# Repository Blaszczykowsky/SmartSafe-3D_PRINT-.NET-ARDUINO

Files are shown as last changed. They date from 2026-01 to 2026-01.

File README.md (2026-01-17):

# Smart Safe - Projekt MARM

Projekt inteligentnego sejfu łączący mechaniczne zabezpieczenia z monitoringiem wizyjnym i zaawansowaną, zdalną weryfikacją tożsamości. System opiera się na mikrokontrolerach ESP8266 i ESP32 (architektura Dual-MCU) oraz dedykowanej aplikacji desktopowej (C# .NET) wykorzystującej analizę obrazu.

## Galeria

| Widok ogólny | Wnętrze |
| :-: | :-: |
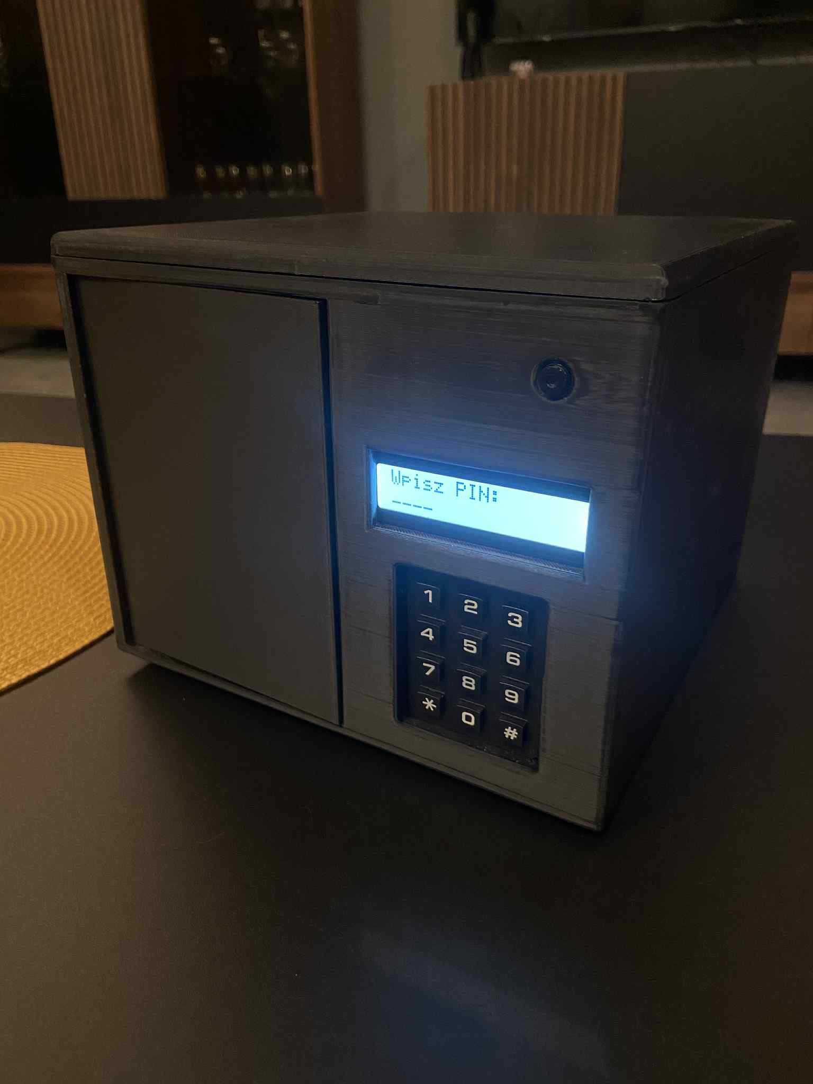
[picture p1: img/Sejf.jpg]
Sejf
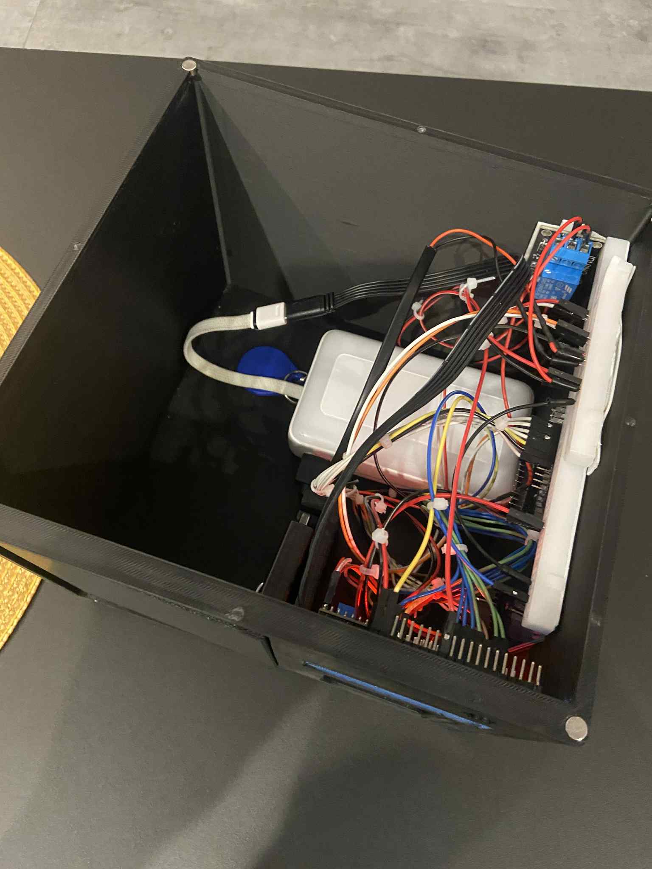
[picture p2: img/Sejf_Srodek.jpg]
Środek
|  |  |

| Interfejs - RFID | Aplikacja - Wykrycie Ruchu
| :-: | :-: |
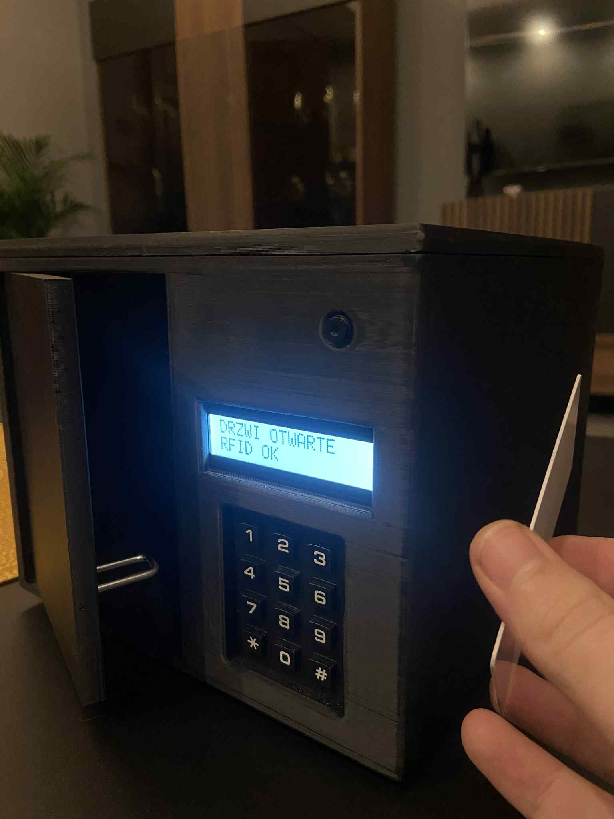
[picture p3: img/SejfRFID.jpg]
RFID
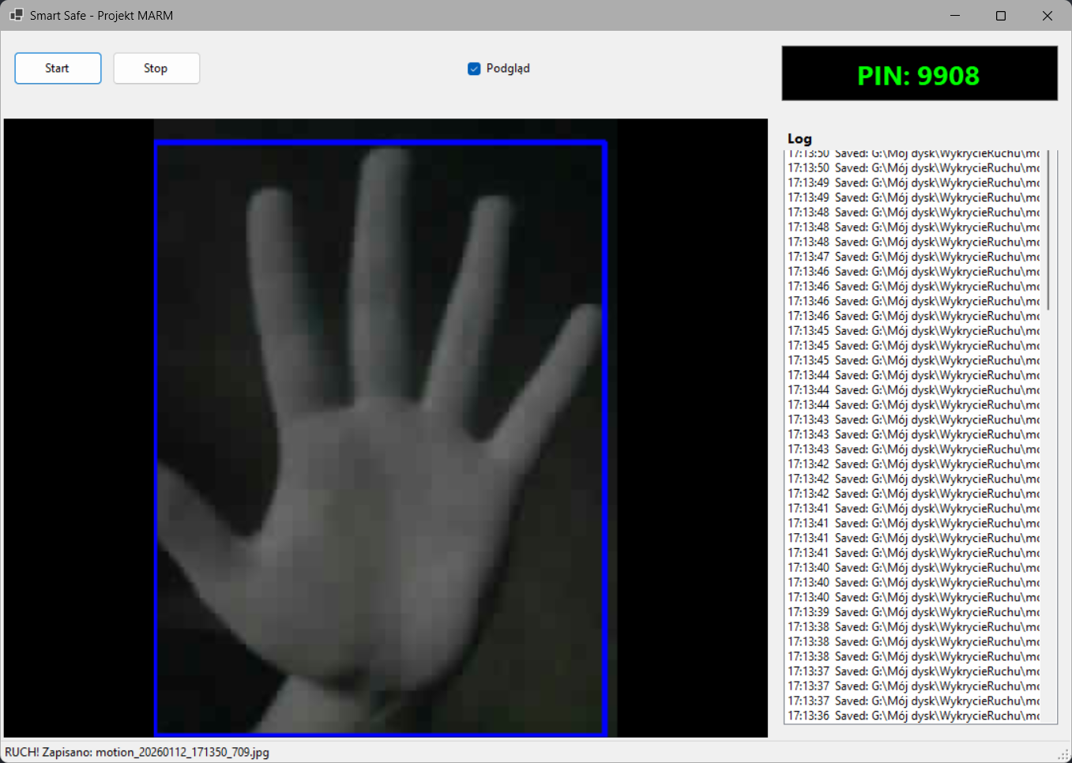
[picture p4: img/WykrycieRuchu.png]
Wykrycie Ruchu
|  |  |

## Główne Funkcjonalności

* **Architektura Dual-MCU:** System został podzielony na dwa mikrokontrolery z powodu ograniczeń sprzętowych modułu ESP32-CAM. Ponieważ większość pinów GPIO w tym module jest zajęta przez obsługę kamery i pamięci PSRAM, niemożliwe było podłączenie wszystkich peryferiów (klawiatury, RFID, LCD, serwa) do jednego układu. Dlatego obsługa RFID i rygla została wydzielona do osobnego układu ESP8266.
* **Komunikacja UDP:** Mikrokontrolery wymieniają między sobą statusy otwarcia (PIN_OK / RFID_OK) w sieci lokalnej, co łączy dwa niezależne moduły w jeden spójny system.
* **Monitoring wideo:** Strumieniowanie obrazu MJPEG z wnętrza sejfu lub otoczenia (zależnie od montażu kamery).
* **Detekcja ruchu:** Aplikacja PC analizuje obraz klatka po klatce przy użyciu algorytmów Computer Vision (OpenCV) i wykrywa zmiany, automatycznie zapisując zdjęcia na dysku po wykryciu aktywności.
* **Zdalna weryfikacja:** Stan systemu i podgląd są dostępne zdalnie przez aplikację.

## System Bezpieczeństwa: Dynamiczna Rotacja PIN (OTP)

Projekt wykorzystuje unikalny mechanizm autoryzacji zbliżony do tokenów bankowych, co eliminuje ryzyko poznania stałego hasła przez osoby niepowołane.

* **Wyłączny dostęp przez aplikację:** Aktualny kod PIN **nie jest stały** i zmienia się cyklicznie (rotacja haseł). Jest on widoczny **wyłącznie** w autoryzowanej aplikacji na komputerze PC. Użytkownik fizycznie znajdujący się przy sejfie nie może go otworzyć bez dostępu do komputera, ponieważ kod jest generowany losowo przez mikrokontroler i ukryty przed otoczeniem.
* **Technologia weryfikacji:** Aplikacja PC komunikuje się z ESP32 poprzez zabezpieczony endpoint HTTP (`/pin`). Odczyt aktualnego kodu wymaga przesłania w nagłówku zapytania specjalnego tokenu (`X-Auth`), co chroni przed nieautoryzowanym podglądem w sieci lokalnej.
* **Podwójna metoda wejścia:** Niezależnie od systemu PIN, sejf posiada czytnik RFID, umożliwiający otwarcie za pomocą zaprogramowanej karty zbliżeniowej (obsługiwane przez ESP8266).

## Lista Elementów (BOM)

Poniżej znajduje się zestawienie kluczowych komponentów wykorzystanych w projekcie.

| Element | Rola w systemie | Link (Przykładowy) |
| :--- | :--- | :--- |
| **ESP32-CAM** | Główna jednostka, serwer wideo, obsługa klawiatury, LCD i Zamka. | [[Link do sklepu](https://pl.aliexpress.com/item/1005008285512156.html?gatewayAdapt=glo2pol)] |
| **ESP (Dowolny)** | Obsługa czytnika RFID. | [[Link do sklepu](https://pl.aliexpress.com/item/1005006418608267.html?gatewayAdapt=glo2pol)] |
| **Czytnik RFID RC522** | Autoryzacja kartami zbliżeniowymi 13.56 MHz. | [[Link do sklepu](https://pl.aliexpress.com/item/1005006949661232.html?gatewayAdapt=glo2pol)] |
| **Klawiatura membranowa 3x4** | Interfejs wprowadzania kodu PIN. | [[Link do sklepu](https://pl.aliexpress.com/item/1005004948322546.html?gatewayAdapt=glo2pol)] |
| **Wyświetlacz LCD 2x16 (I2C)** | Wyświetlanie komunikatów systemowych. | [[Link do sklepu](https://pl.aliexpress.com/item/1005003785193247.html?gatewayAdapt=glo2pol)] |
| **Zamek** | Fizyczna blokada drzwi. | [[Link do sklepu](https://pl.aliexpress.com/item/1005004775883283.html?gatewayAdapt=glo2pol)] |
| **Moduł przekaźnika** | Do obsługi zamka. | [[Link do sklepu](https://botland.com.pl/przekazniki-przekazniki-arduino/8228-modul-przekaznika-iduino-1-kanal-styki-10a250vac-cewka-5v-5903351241229.html)] |
| **Magnesy 6x3 (x8 sztuk)** | Jako połączenie klapki z resztą sejfu | [[Link do sklepu](https://allegro.pl/produkt/magnes-neodymowy-walcowy-6x3-mm-hunter-n45-udzwig-0-90-kg-10-szt-df3e8ef4-5a3c-48db-953a-896c9a9c482a?offerId=7815010546)] |

## Projekt 3D (STL)

Obudowa sejfu została zaprojektowana w środowisku **SolidWorks**. Konstrukcja uwzględnia dedykowane mocowania dla elektroniki i spasowanie elementów ruchomych (drzwi, rygiel).

Pliki `.STL` gotowe do druku się w katalogu `/Stl's`:
* `Korpus.stl` - Główna bryła sejfu.
* `Drzwi.stl` - Drzwi.
* `Rurka.stl` - Jako oś obrotu drzwi.
* `Daszek.stl` - Pokrywa sejfu.

## Opis Oprogramowania

### 1. Moduł Zamka (ESP8266)
Plik: `ESP8266_RFID.ino`
Odpowiada za obsługę peryferiów, dla których zabrakło pinów w głównym module ESP32.
* Obsługuje czytnik RFID MFRC522 (weryfikacja UID karty).

### 2. Moduł Interfejsu i Kamery (ESP32)
Plik: `ESP32_LCD_KEYPAD_CAMERA_LOCK.ino`
Pełni rolę huba komunikacyjnego i interfejsu użytkownika.
* Uruchamia serwer **Camera Web Server** do streamingu wideo.
* Zarządza logiką zmiennego PINu i wystawia go przez API REST.
* Obsługuje klawiaturę membranową i wyświetlacz LCD.
* *Uwaga:* Kod odpowiedzialny za inicjalizację kamery i obsługę MJPEG bazuje na oficjalnych przykładach Espressif Systems, które zostały zmodyfikowane i zintegrowane z resztą systemu (obsługa Keypada, UDP i autorskiej logiki PIN).

### 3. Aplikacja Desktopowa (C# .NET)
Plik: `Program.cs` / Projekt Visual Studio
Centrum monitoringu napisane w technologii Windows Forms.
* **Stream Wideo:** Odbiera strumień MJPEG (`http://<IP>:81/stream`) i wyświetla go w oknie aplikacji.
* **Bezpieczeństwo:** Pobiera aktualny, rotujący PIN z zabezpieczonego endpointu (`http://<IP>:8080/pin`) używając tokenu autoryzacyjnego `X-Auth`.
* **Computer Vision:** Realizuje algorytm detekcji ruchu przy użyciu biblioteki **OpenCvSharp**. Porównuje klatki (`Absdiff`), proguje zmiany (`Threshold`) i analizuje kontury. Jeśli zmiana przekracza zdefiniowany próg, następuje automatyczny zapis zdjęcia dowodowego na dysk.

## Konfiguracja i Uruchomienie

1.  **Sieć WiFi:** W obu plikach `.ino` należy uzupełnić zmienne `ssid` oraz `pass`.
2.  **Adresacja IP:**
    * W kodzie ESP8266 ustaw adres docelowy ESP32 (`esp32_ip`).
    * W kodzie ESP32 ustaw adres docelowy ESP8266 (`esp8266_ip`).
    * Zalecane jest ustawienie stałych adresów IP (DHCP Reservation) w routerze.
3.  **Token Autoryzacyjny:** Upewnij się, że `AUTH_TOKEN` w kodzie ESP32 jest taki sam jak `AuthToken` w aplikacji C#.
4.  **Aplikacja PC:**
    * W pliku `Program.cs` zaktualizuj `StreamUrl` oraz `PinUrl`.
    * Skonfiguruj folder zapisu zdjęć w zmiennej `SaveDir`.

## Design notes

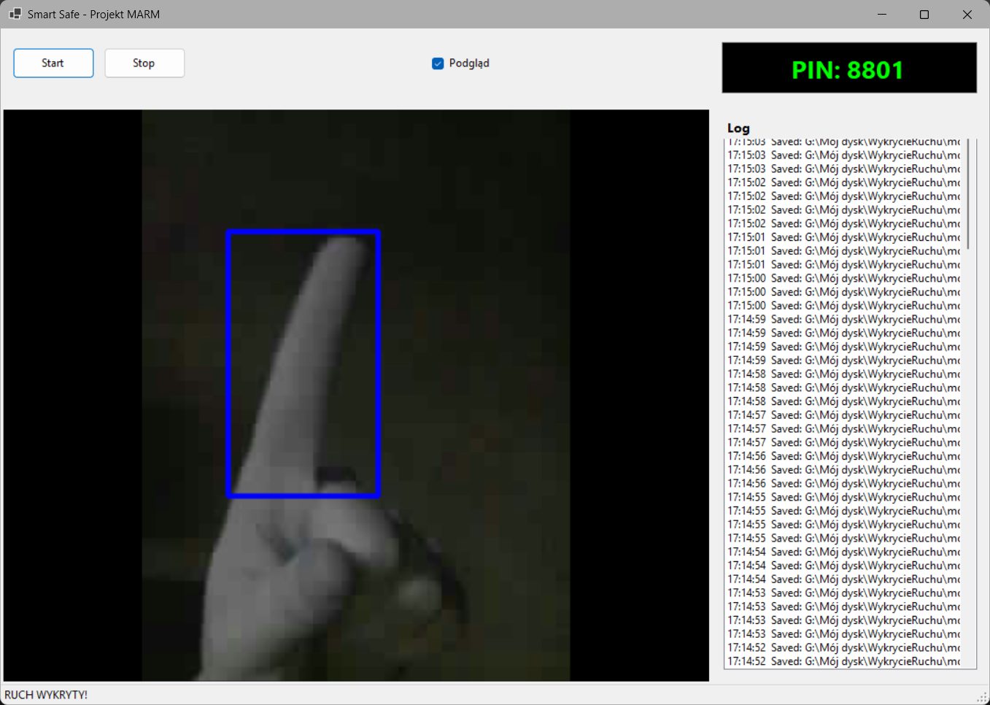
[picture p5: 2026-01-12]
img/WykrycieRuchu2.png

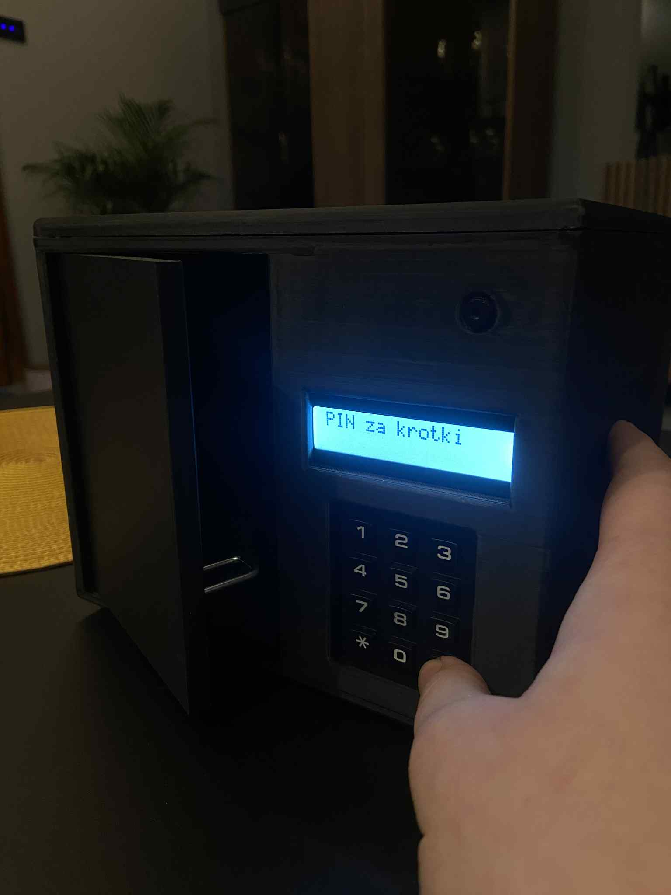
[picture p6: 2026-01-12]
img/Sejf_KrotkiPin.jpg

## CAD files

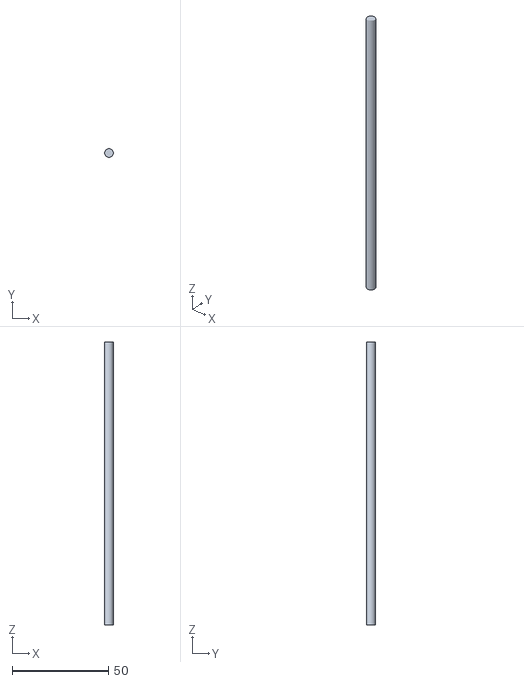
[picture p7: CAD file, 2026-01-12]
Stl's/Rurka.STL
4.50 x 4.50 x 147.0

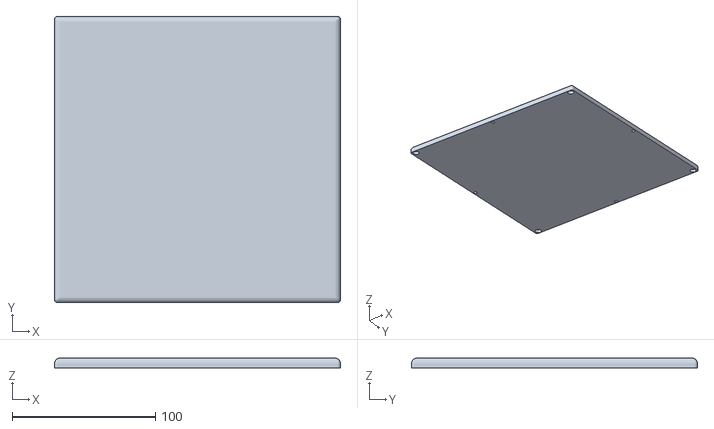
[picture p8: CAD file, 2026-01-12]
Stl's/Daszek.STL
200.0 x 200.0 x 7.00

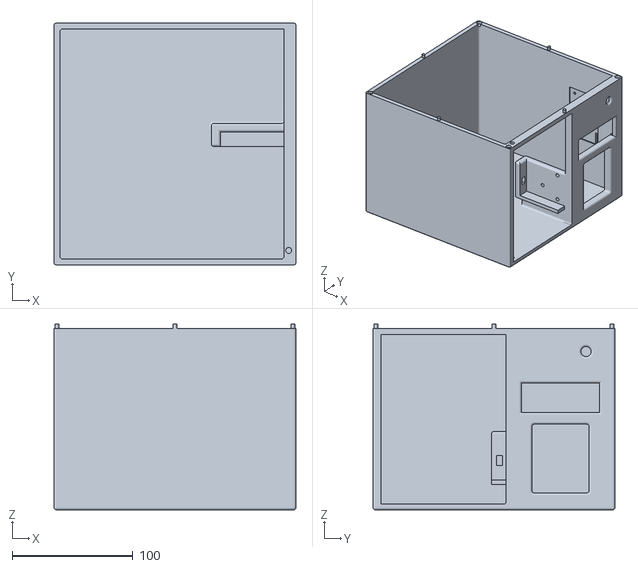
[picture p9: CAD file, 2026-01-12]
Stl's/Korpus.STL
200.0 x 200.0 x 153.5

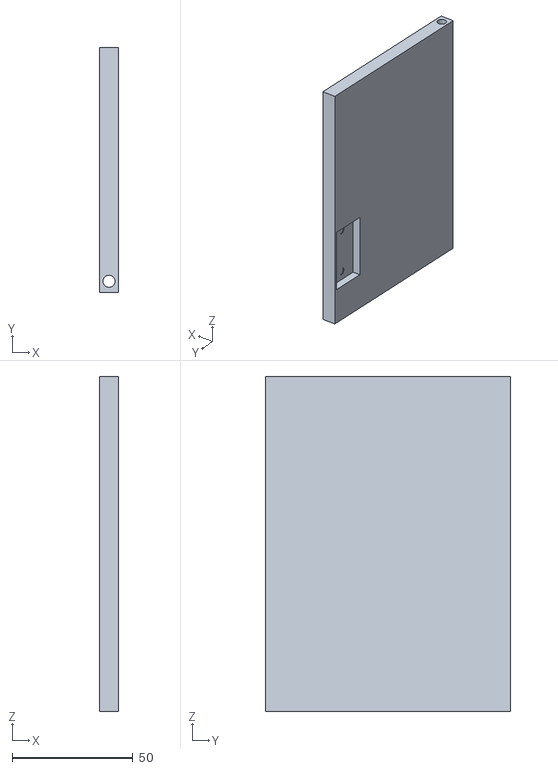
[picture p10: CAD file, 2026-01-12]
Stl's/Drzwi.STL
8.00 x 101.7 x 139.0

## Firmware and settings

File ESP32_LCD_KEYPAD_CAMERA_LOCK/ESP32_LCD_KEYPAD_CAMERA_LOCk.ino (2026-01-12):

#include <Arduino.h>
#include <WiFi.h>
#include "board_config.h"
#include <WiFiUdp.h>

#include "CameraService.h"
#include "Display.h"
#include "KeypadInput.h"
#include "PinLogic.h"
#include "Pins.h"
#include "LockService.h"

static const char *AUTH_TOKEN = "SEJF_SHARED_TOKEN_123";

static String enteredPin;

WiFiUDP udp;
const uint16_t UDP_PORT = 4210;

enum Msg : uint8_t {
  MSG_RFID_OK  = 2,
  MSG_RFID_BAD = 3
};

static void granAccess(const char* reason) {
  Serial.printf("Nadano dostep(%s)", reason);

  if(doorIsOpen()){
    showTemp("DRZWI OTWARTE","RFID OK", 1200);
    return;
  }

  LockService_pulse(LOCK_PULSE_MS);
  showTemp("RFID OK","SEJF OTWARTY", 1200);
}

static void handleUdpFromEsp8266() {
  int p = udp.parsePacket();
  if (p <= 0) return;

  uint8_t b = 0;
  udp.read(&b, 1);

  if (b == MSG_RFID_OK){granAccess("RFID");}
  if (b == MSG_RFID_BAD){showTemp("RFID FAIL","",900);}
}

static inline bool doorIsOpen() {
#if defined(DOOR_SWITCH_ACTIVE_LOW) && (DOOR_SWITCH_ACTIVE_LOW == 1)
  return digitalRead(PIN_DOOR_SWITCH) == LOW;
#else
  return digitalRead(PIN_DOOR_SWITCH) == HIGH;
#endif
}

static uint32_t showUntilMs = 0;
static bool showingResult = false;

static void showTemp(const char* l1, const char* l2, uint16_t ms) {
  Display_showLine(l1, l2);
  showUntilMs = millis() + ms;
  showingResult = true;
}

void setup() {
  Serial.begin(115200);
  Serial.setDebugOutput(true);
  Serial.println();
  delay(300);

  Serial.printf("PSRAM: %s\n", psramFound() ? "OK" : "NOT FOUND");
  randomSeed((uint32_t)esp_random());

  Display_begin();
  Display_prompt();

  pinMode(PIN_DOOR_SWITCH, INPUT_PULLUP);

  LockService_begin(PIN_LOCK_RELAY, LOCK_RELAY_ACTIVE_HIGH);

  if (!CameraService_begin()) {
    Display_showLine("Cam init FAIL", "");
    return;
  }

  WiFi.mode(WIFI_AP);
  WiFi.softAP("SEJF_CAM", "12345678");

  Serial.print("AP IP: ");
  Serial.println(WiFi.softAPIP());

  udp.begin(UDP_PORT);

  CameraService_startServer();

  PinLogic_begin(AUTH_TOKEN);

  Display_prompt();
}

void loop() {
  LockService_tick();

  handleUdpFromEsp8266();

  PinLogic_tick();

  PinLogic_handleClient();

  if (showingResult && (int32_t)(millis() - showUntilMs) >= 0) {
    showingResult = false;
    enteredPin = "";
    Display_prompt();
  }

  char k = KeypadInput_getKey();
  if (!k) {
    delay(2);
    return;
  }

  if (showingResult) {
    showingResult = false;
    showUntilMs = 0;
    enteredPin = "";
    Display_prompt();
    delay(2);
    return;
  }

  if (k == '*') {
    enteredPin = "";
    Display_prompt();
    delay(2);
    return;
  }

  if (k == '#') {
    if (enteredPin.length() != 4) {
      showTemp("PIN za krotki", "", 800);
      enteredPin = "";
      delay(2);
      return;
    }

    bool ok = PinLogic_isPinCorrect(enteredPin);

    Serial.printf("[SAFE] entered=%s current=%s => %s\n",
                  enteredPin.c_str(),
                  PinLogic_getCurrentPin(),
                  ok ? "OK" : "WRONG");

    if (ok) {
      if (doorIsOpen()) {
        showTemp("DRZWI OTWARTE", "ZAMKA NIE TRZEBA", 1200);
      } else {
        LockService_pulse(LOCK_PULSE_MS);
        Display_result(true);
        showingResult = true;
        showUntilMs = millis() + 1200;
      }
    } else {
      Display_result(false);
      showingResult = true;
      showUntilMs = millis() + 1200;
    }

    enteredPin = "";
    delay(2);
    return;
  }

  if (k >= '0' && k <= '9') {
    if (enteredPin.length() < 4) {
      enteredPin += k;
      Display_showMask(enteredPin.length());
    }
  }

  delay(2);
}

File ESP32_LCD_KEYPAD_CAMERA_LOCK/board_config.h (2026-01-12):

#pragma once

#define PWDN_GPIO_NUM   -1
#define RESET_GPIO_NUM  -1

#define XCLK_GPIO_NUM   15
#define SIOD_GPIO_NUM    4
#define SIOC_GPIO_NUM    5

#define Y2_GPIO_NUM     11
#define Y3_GPIO_NUM      9
#define Y4_GPIO_NUM      8
#define Y5_GPIO_NUM     10
#define Y6_GPIO_NUM     12
#define Y7_GPIO_NUM     18
#define Y8_GPIO_NUM     17
#define Y9_GPIO_NUM     16

#define VSYNC_GPIO_NUM   6
#define HREF_GPIO_NUM    7
#define PCLK_GPIO_NUM   13

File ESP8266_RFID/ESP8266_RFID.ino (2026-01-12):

#include <Arduino.h>
#include <ESP8266WiFi.h>
#include <WiFiUdp.h>
#include <SPI.h>
#include <MFRC522.h>

const char* ssid = "SEJF_CAM";
const char* pass = "12345678";

WiFiUDP udp;
const uint16_t UDP_PORT = 4210;

IPAddress esp32_ip = WiFi.gatewayIP();

enum Msg : uint8_t {
  MSG_PIN_OK   = 1,
  MSG_RFID_OK  = 2,
  MSG_RFID_BAD = 3
};

static void sendToEsp32(Msg msg) {
  uint8_t b = (uint8_t)msg;
  for (int i = 0; i < 3; i++) {
    udp.beginPacket(esp32_ip, UDP_PORT);
    udp.write(&b, 1);
    udp.endPacket();
    delay(20);
  }
}

#define SS_PIN   D8 
#define RST_PIN  D4 
MFRC522 mfrc522(SS_PIN, RST_PIN);

const byte allowed[][4] = { {0xB5, 0x57, 0xCF, 0x06} };
const int allowedCount = sizeof(allowed)/sizeof(allowed[0]);

bool uidMatches(const byte* uid) {
  for (int i=0;i<allowedCount;i++){
    bool ok=true;
    for(int j=0;j<4;j++){
      if(allowed[i][j]!=uid[j]){ ok=false; break; }
    }
    if(ok) return true;
  }
  return false;
}

void sendEventToEsp32(uint8_t msg) {
  for (int i=0;i<3;i++) {
    udp.beginPacket(esp32_ip, UDP_PORT);
    udp.write(&msg, 1);
    udp.endPacket();
    delay(20);
  }
}

void unlock(const char* reason) {
  Serial.print("ZAMEK OTWARTY (");
  Serial.print(reason);
  Serial.println(")");
}

void handleUdp() {
  int p = udp.parsePacket();
  if (p <= 0) return;

  uint8_t b=0;
  udp.read(&b, 1);
  if (b == MSG_PIN_OK) unlock("PIN z ESP32");
}

void setup() {
  Serial.begin(115200);
  delay(300);

  WiFi.setSleep(false);

  WiFi.mode(WIFI_STA);
  WiFi.begin(ssid, pass);
  while (WiFi.status() != WL_CONNECTED) delay(300);
  esp32_ip = WiFi.gatewayIP();
  Serial.print("Gateway (ESP32) = ");
  Serial.print(esp32_ip);

  udp.begin(UDP_PORT);
  Serial.printf("[ESP8266] UDP listen: %u\n", UDP_PORT);

  SPI.begin();
  mfrc522.PCD_Init();
  Serial.println("[RFID] RC522 init OK");
  Serial.println("Przylóż kartę...");
}

void loop() {
  static unsigned long last = 0;
  if (millis() - last > 1000) {
    last = millis();
    WiFi.RSSI();
  }

  handleUdp();

  if (!mfrc522.PICC_IsNewCardPresent()) return;
  if (!mfrc522.PICC_ReadCardSerial()) return;

  Serial.print("UID: ");
  for (byte i=0;i<mfrc522.uid.size;i++) Serial.printf("%02X ", mfrc522.uid.uidByte[i]);
  Serial.println();

  bool ok = (mfrc522.uid.size >= 4) && uidMatches(mfrc522.uid.uidByte);

  if (ok) {
    unlock("RFID");
    sendToEsp32(MSG_RFID_OK);
  } else {
    Serial.println("BRAK DOSTEPU");
    sendToEsp32(MSG_RFID_BAD);
  }

  mfrc522.PICC_HaltA();
  mfrc522.PCD_StopCrypto1();
  delay(300);
}

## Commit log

2026-01-12 Pliki do wydruku sejfu
    [Daszek.STL, Drzwi.STL, Korpus.STL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]
2026-01-12 Dodanie folderu zawierającego kod dla ESP32-S3 CAM
    W folderze zrobiony został podział na pliki z racji na rozbudowaną funkcjonalność.
    [partitions.csv]
2026-01-12 Dodanie folderu z kodem dla ESP8266
    Mikrokontroler esp8266 został użyty tylko z powodu brakujących pinów GPIO na esp32
